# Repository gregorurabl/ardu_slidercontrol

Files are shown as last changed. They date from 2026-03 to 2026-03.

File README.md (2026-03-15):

# Slidercontrol V2.1
### Motorized Camera Slider - Sources and Hardware Documentation

**Author:** Gregor Urabl | [gregorurabl.at](https://gregorurabl.at)  
**Version:** 2.1  
**Platform:** Arduino Mega 2560 (AZ-Delivery Clone)  
**Slider:** Rollei / iFootage Shark S1

**Photos:** https://github.com/gregorurabl/ardu_slidercontrol/tree/main/Fotos_Videos

**Videos:** https://drive.google.com/drive/folders/1h0wJf8_ykMVB8sSwVJ3sm4PEZuROGbLa

> **Work in Progress** - This documentation is incomplete and subject to change without notice.

> **Disclaimer:** This project is shared for educational and personal reference purposes only. No support is provided. If you choose to replicate this project, you do so entirely at your own risk. The author accepts no responsibility for any damage to equipment, components, cameras, or any other property, nor for any personal injury, that may result from building or operating this or a similar system. Working with stepper motors, motor drivers and external power supplies involves voltages and currents that can cause permanent hardware damage if wired incorrectly. Always verify your wiring before applying power.

image (8)

---

## Table of Contents

1. [Sources & Libraries](#1-sources--libraries)
   - [1.1 Project Base](#11-project-base)
   - [1.2 Arduino Libraries](#12-arduino-libraries)
    - [Schematic](#schematic)
2. [Hardware](#2-hardware)
   - [2.1 Main Components](#21-main-components)
   - [2.2 Hardware History & Incidents](#22-hardware-history--incidents)
   - [2.3 Stepper Motor & Gearbox](#23-stepper-motor--gearbox)
   - [2.4 Camera Trigger Circuit](#24-camera-trigger-circuit)
   - [2.5 Optional Ultrasonic End-Stop Sensor](#25-optional-ultrasonic-end-stop-sensor)
   - [2.6 Controller Housing](#26-controller-housing)
3. [Pin Reference (Arduino Mega 2560)](#3-pin-reference-arduino-mega-2560)
   - [3.1 TFT Display](#31-tft-display)
   - [3.2 Touchscreen (Resistive)](#32-touchscreen-resistive)
   - [3.3 Stepper Motor Driver (A4988)](#33-stepper-motor-driver-a4988)
   - [3.4 Sonar / Camera Trigger (shared)](#34-sonar--camera-trigger-shared)
4. [Desktop Remote (Python)](#4-desktop-remote-python)
---

## Overview

Slidercontrol V2.1 is a fully self-contained motorized camera slider controller built around an Arduino Mega 2560. It drives a NEMA 17 stepper motor with planetary gearbox via an A4988 driver and provides a touchscreen UI on a 3.5" TFT shield. An optional ultrasonic sensor acts as an automatic end-stop, and a galvanically isolated camera trigger fires a Canon DSLR in sync with slider movement for timelapse sequences.

## Planned Features

| Feature | Status |
|---|---|
| Timelapse runtime pre-calculation | Planned - display estimated total duration before a timelapse run starts, based on distance, subdivisions, delay and motor speed |
| Desktop Remote Control | BETA ready - plattform (Windows/Linux/Mac OS) independent GUI for a serial remote control (Python)|
| App Remote Control | Planned - a bluetooth remote control via amartphone app.|

### Project History - Fork of Mega-Testberichte.de

This project started as a close implementation of the [Mega-Testberichte.de motorized slider guide](https://www.mega-testberichte.de/artikel/kameraslider-motorisieren) by Marco Kleine-Albers, which I recommend consulting alongside this documentation for build photos, a step-by-step walkthrough and additional context - it is the more visually complete reference.

Over time the project diverged significantly in both hardware and software. Key reasons for branching off:

- **MobaTools instead of AccelStepper:** The original guide uses AccelStepper, which generates blocking code during motor movement. When the ultrasonic end-stop sensor was added to the system (which predates the camera trigger), non-blocking motor control became a hard requirement - the sonar loop must keep running while the motor moves. MobaTools, developed by MicroBahner as an Arduino library for model railroaders (MOdel BAhn), provides a fully non-blocking stepper implementation and is optimized for fine-grained, precise movement control - exactly what smooth camera slider travel requires. The library origins in model rail applications mean it handles slow, precise, repeatable motion particularly well.
- **Planetary gearbox motor:** The motor choice with integrated 1:14 gearbox changes the tuning, microstepping strategy and speed range significantly compared to a standard NEMA 17.
- **Camera trigger system:** An entirely new hardware and software subsystem not present in the original guide.
- **Serial remote control:** Added for computer-controlled timelapse sequences.

The original guide remains the better starting point for someone new to the project. This documentation focuses on what has changed, the reasoning behind it, and the specifics of this particular build.

### Tested Payloads

The system has been tested with the following camera setups on a horizontal slider:

| Setup | Approx. Weight | Result |
|---|---|---|
| Canon EOS 7D + lens | ~1.5 kg | Reliable at all speed settings |
| Canon EOS 5D Mark IV + lens | ~2.5 kg | Reliable at all speed settings |
| Canon EOS C400 (fully rigged) | ~6 kg | Moved without issues |

The Canon C400 test in particular is notable - a cinema camera fully rigged approaches the practical limits of the slider platform itself.

#### Theoretical Maximum Load

The following is a rough estimate based on component datasheets. Real-world load capacity depends heavily on slider bearing condition, belt tension, incline angle and chosen speed.

**Motor output torque (at gearbox output shaft):**
```
T_out = T_motor × gear_ratio × efficiency
T_out = 0.52 Nm × 13.73 × 0.80 = ~5.7 Nm (theoretical peak)
```
The gearbox max permissible continuous torque is rated at **3 Nm**, which is the practical ceiling regardless of motor output.

**Force available at belt/drive:**  
Assuming a typical belt pulley radius of ~10–15 mm:
```
F = T / r = 3 Nm / 0.012 m = 250 N (~25 kg-equivalent)
```

**Real limiting factors (in order of likely constraint):**
1. **Slider rated payload** - the iFootage Shark S1 is rated for approximately 8 kg. This is the most restrictive limit for horizontal use.
2. **Gearbox max continuous torque** - 3 Nm (5 Nm momentary peak)
3. **Gearbox shaft max axial load** - 50 N (~5 kg linear force along the shaft axis)
4. **A4988 current limit** - set to ~1.18 A in this build (~70% of rated); higher current settings increase torque headroom but also heat

For horizontal use, the slider's own payload rating is the practical limit. The motor and gearbox have significant torque headroom for loads within that rating. Inclined or vertical use would require a separate calculation and is untested.

> These figures are theoretical estimates derived from component datasheets and standard engineering assumptions. They are not guaranteed values. Do not exceed the rated capacity of your slider platform.

### What This Project Does

The controller moves a camera along a slider rail at configurable speed, distance and direction. Three operating modes are available:

- **Normal Run** - moves the slider a set distance at a set speed, with optional return to start position
- **Manual Run** - continuous motor rotation for free-form positioning, start/stop via touchscreen
- **Timelapse** - divides the total travel into equal sub-steps, pauses at each position for a configurable delay, and optionally fires the camera shutter at every stop

All parameters (speed, distance, ramp, delay, subdivisions) are adjusted on the touchscreen. The controller can also be operated via serial commands over USB.

### What You Need

**Electronics**
| Item | Notes |
|---|---|
| Arduino Mega 2560 (or clone) | AZ-Delivery clone confirmed working |
| 3.5" parallel TFT LCD shield, 480×320 | MCUFRIEND_kbv-compatible |
| A4988 stepper driver breakout board | Check R_CS marking before use (see [3.3](#33-stepper-motor-driver-a4988)) |
| NEMA 17 stepper motor | 17HS19-1684s-PG14 with 1:14 planetary gearbox used here |
| 100 µF electrolytic capacitor | Motor supply decoupling, placed close to A4988 |
| 12V / 5A DC power supply | Motor supply |
| USB power bank or 5V supply | Arduino logic supply |
| 4N33 optocoupler + 390 Ω resistor | Camera trigger circuit (optional) |
| 2.5 mm TRS female jack | Camera trigger output (optional) |
| 2.5 mm male to Canon N3 female cable | Off-the-shelf adapter cable (optional) |
| HC-SR04 ultrasonic sensor | End-stop safety (optional, mutually exclusive with camera trigger) |

**Mechanical**
- Camera slider with accessible drive shaft (e.g. Rollei / iFootage Shark S1)
- 3D-printed motor mount adapted to your slider model (see [1.1 Sources](#11-project-base))

**Tools**
- Soldering iron
- Multimeter - required for A4988 current limit calibration

### Wiring Overview

```
USB Power Bank ──────────────────────── Arduino Mega 2560
                                               │
                         ┌─────────────────────┼──────────────────┐
                         │                     │                  │
                    TFT Shield            A4988 Driver        D47 / D49
                  (direct plug-in         VDD  ← 5V           Camera trigger
                   onto Mega headers)     GND  ← GND (logic)  or HC-SR04
                                          EN   ← D23
                                          STEP ← D25
                                          DIR  ← D27
                                               │
12V / 5A PSU ──── [100 µF] ──── VMOT          │
             └──────────────── GND (motor)    │
                                          1A / 1B / 2A / 2B
                                               │
                                         Stepper Motor
```

The TFT shield plugs directly onto the Arduino Mega headers - no separate display wiring required. Motor, A4988 and power supply are wired as a separate circuit. The camera trigger is a standalone optocoupler circuit connected to D47 and GND.

**Important:** The Arduino (logic) and the motor driver (power) use separate ground connections that share a common reference point only at the DC jack. See [Ground Separation](#33-stepper-motor-driver-a4988) for details.

### Serial / USB Remote Control

The controller can be operated remotely over USB via any serial terminal (e.g. Arduino Serial Monitor, PuTTY) at **115200 baud**.

Commands are comma-separated strings terminated with a newline (`\n`). Each field can optionally carry a label prefix using a colon (`label:value`) - the parser strips everything up to and including the last colon, so both formats are accepted.

**Command format:**

```
mode,speed,distance,ramp,time,steps
```

| Index | Field | Description |
|---|---|---|
| 0 | mode | `normal`, `timelapse`, or `rth` (case-insensitive) |
| 1 | speed | Motor speed (steps/s) |
| 2 | distance | Travel distance in steps |
| 3 | ramp | Ramp/acceleration length in steps |
| 4 | time | Timelapse delay between stops in seconds |
| 5 | steps | Number of timelapse subdivisions (minimum 2) |

**Examples:**

```
normal,600,33000,0,0,2
timelapse,400,33000,0,30,10
rth,0,0,0,0,0
```

Unused fields still need to be present as placeholders. For `rth`, all fields after index 0 are ignored. The controller responds with status messages over the same serial connection.

---

## 1. Sources & Libraries

### 1.1 Project Base

This project is based on a guide by Marco Kleine-Albers (Mega-Testberichte.de) and was adapted and extended for use with Adafruit TFT and MobaTools by Gregor Urabl (gregorurabl.at), optimized for the Rollei/iFootage Shark S1 slider and a planetary-geared stepper motor.

| Source | Details | URL |
|---|---|---|
| Original Guide | Marco Kleine-Albers, Mega-Testberichte.de - complete build guide incl. schematic, parts list and software base | [mega-testberichte.de/artikel/kameraslider-motorisieren](https://www.mega-testberichte.de/artikel/kameraslider-motorisieren) ✅ |
| Adaptation & Extension | Gregor Urabl (gregorurabl.at) - adapted for Adafruit TFT & MobaTools, optimized for planetary geared stepper, camera trigger extension | [gregorurabl.at](https://gregorurabl.at) |
| Display | Niunion 3.5" TFT LCD Shield, 480×320, 8-bit parallel, resistive touchscreen, MCUFRIEND_kbv-compatible - ASIN: B08KG51VLW | [amazon.de](https://www.amazon.de/dp/B08KG51VLW) ✅ |
| Motor Mount (3D Print) | Parametric mount for iFootage Shark S1 motorization. Author: Benjamin (Hamburg). Original page no longer available. | mein-slider.de/ifootage-shark-s1-motorhalterung ❌ offline |
| Camera Trigger Reference | Martyn Currey - "Using an Arduino and an optocoupler to activate a camera shutter" - basis for optocoupler circuit design, resistor calculation and jack pinout | [martyncurrey.com/activating-the-shutter-release](https://www.martyncurrey.com/activating-the-shutter-release/) ✅ |
| Microstepping Reference | A4988 driver pin mapping and microstepping mode table | [lastminuteengineers.com](https://lastminuteengineers.com/a4988-stepper-motor-driver-arduino-tutorial/) ✅ |
| A4988 Product & Datasheet | Pololu A4988 stepper driver carrier - official product page incl. schematic, pinout and datasheet | [pololu.com/product/1182](https://www.pololu.com/product/1182) ✅ |
| MobaTools Library | Arduino library by MicroBahner (f-pm+gh@mailbox.org). Originally developed for model railroaders (MOdel BAhn), optimized for precise, fine-grained stepper control - which maps directly to the needs of smooth camera slider movement. Used here as a non-blocking replacement for AccelStepper. | [github.com/MicroBahner/MobaTools](https://github.com/MicroBahner/MobaTools) ✅ |

### 1.2 Arduino Libraries

| Library | Purpose | Source |
|---|---|---|
| Adafruit_GFX | Core graphics library | Adafruit Industries |
| Adafruit_TFTLCD | TFT display driver | Adafruit Industries |
| TouchScreen | Resistive touchscreen input | Adafruit Industries |
| MCUFRIEND_kbv | Hardware-specific TFT driver | David Prentice (GitHub) |
| MobaTools | Stepper motor and timer control. Non-blocking implementation, originally developed for model railroaders (MOdel BAhn) by MicroBahner - optimized for fine-grained, precise movement. Replaces AccelStepper to enable concurrent sonar and motor operation. | [github.com/MicroBahner/MobaTools](https://github.com/MicroBahner/MobaTools) |
| NewPing | HC-SR04 ultrasonic sensor | Tim Eckel (Arduino Library Manager) |

---

## Schematic

SliderControl_Schematic

The KiCad schematic file is at `KiCad/Slidercontrol_V2_1_Corrected.kicad_sch`.

The schematic covers:
- Arduino Mega 2560 with all used pin connections
- A4988 driver with motor power supply, 100 µF decoupling capacitor and stepper motor
- Camera trigger circuit (4N33, R1, 2.5 mm jack)
- HC-SR04 ultrasonic sensor (optional, shared pins D47/D49)
- TFT shield pin mapping

Also refer to the pin reference tables in [Section 3](#3-pin-reference-arduino-mega-2560) and the circuit diagrams in [Section 2.4](#24-camera-trigger-circuit) and [Section 3.3](#33-stepper-motor-driver-a4988).

---

## 2. Hardware

### 2.1 Main Components

| Component | Description / Specification |
|---|---|
| Microcontroller | AZ-Delivery Arduino Mega 2560 Clone (replacement after hardware incident, see [2.2](#22-hardware-history--incidents)) |
| Display | 3.5" Parallel TFT Shield, MCUFRIEND_kbv-compatible, 480×320 px |
| Stepper Motor | Stepperonline 17HS19-1684s-PG14 - 1.8°/step - Planetary Gearbox 1:14 |
| Motor Driver | A4988 (final version; TMC2209 tested previously, see [2.2](#22-hardware-history--incidents)) |
| Slider Platform | Rollei / iFootage Shark S1 |
| Camera Trigger | 4N33 optocoupler + 390 Ω resistor + 2.5 mm TRS jack |
| Ultrasonic Sensor (opt.) | HC-SR04 (end-stop safety) |

---

### 2.2 Hardware History & Incidents

#### TMC2209 V2.0 - tested, not used in final version

A test with a TMC2209 V2.0 Ultra Silent 2.5A stepper driver resulted in a cable fire and the burnout of the Arduino Mega's DC-In voltage regulator. The driver was also destroyed in the process. The exact root cause could not be conclusively determined; possible contributing factors include undersized wiring, a pre-existing defect in the DC-In regulator, or an overcurrent condition caused by the driver.

Apart from slightly quieter motor operation, the TMC2209 showed no meaningful improvement in motion smoothness compared to the A4988. The stepper motor's planetary gearbox (1:14) already provides inherently smooth and consistent motion, which largely eliminates the benefit of Stealthchop. The final version therefore uses the A4988.

#### AZ-Delivery Mega 2560 Clone - replacement after hardware incident

Following the failure of the original Arduino Mega 2560, the system runs successfully on an AZ-Delivery Mega 2560 clone. Pin mapping and feature set are fully compatible with the original; all documented functions operate reliably on the clone.

---

### 2.3 Stepper Motor & Gearbox

The Stepperonline 17HS19-1684s-PG14 features an integrated planetary gearbox with a 1:14 ratio, providing high holding torque at low RPM - well suited for smooth, consistent slider travel. Microstepping is disabled in firmware because the gearbox already provides sufficient mechanical smoothing.

| Parameter | Value |
|---|---|
| Step angle | 1.8° (200 full steps/rev) |
| Gearbox ratio | 1:14 |
| Microstepping | Disabled (pins M1–M3 NC) |
| Steps/rev in firmware | 3200 (200 × 16) - constant retained for reference |

> **Note:** The 3200 steps/rev constant in the code reflects the full microstepping configuration. With the planetary gearbox and microstepping disabled, effective mechanical resolution differs. The constant is kept for potential use without the gearbox.

---

### 2.4 Camera Trigger Circuit

The camera trigger provides galvanic isolation between the Arduino and the camera using a 4N33 optocoupler. The Arduino is directly wired into the optocoupler circuit. The optocoupler output is connected via a soldered cable to a **2.5 mm TRS female jack** permanently mounted on the controller housing. From there, a commercially available **2.5 mm male to Canon N3 female adapter cable** connects to the camera.

The circuit design follows the approach described by Martyn Currey ([martyncurrey.com/activating-the-shutter-release](https://www.martyncurrey.com/activating-the-shutter-release/)), adapted for the 4N33 with a 390 Ω input resistor.

#### Signal Chain

```
Arduino D47
    │ (direct wiring)
    ▼
Optocoupler circuit (4N33 + R1 390 Ω)
    │ (soldered cable)
    ▼
2.5 mm TRS Female Jack  ←── permanently mounted on housing
    │ (commercial cable: 2.5 mm Male → Canon N3 Female)
    ▼
Camera (Canon N3)
```

#### How It Works

The Canon N3 connector places approximately 3.2V on the shutter and focus lines - **this voltage is supplied by the camera itself**, not by the Arduino. Triggering is achieved by **shorting the shutter line to ground** via the optocoupler. The optocoupler ensures there is no electrical connection between the Arduino circuit and the camera circuit, protecting the camera from any voltage on the controller side.

#### Circuit

```
Arduino D47 ──── R1 (390 Ω) ──── 4N33 Pin 1 (Anode)
                                  4N33 Pin 2 (Cathode) ──── Arduino GND
                                  4N33 Pin 5 (Collector) ── Jack Tip   ──[cable]── N3 Shutter (~3.2V)
                                  4N33 Pin 4 (Emitter) ──── Jack Sleeve ──[cable]── N3 GND
                                  4N33 Pin 3 (Base) ──── NC
                                  Jack Ring ──── NC         ──[cable]── N3 Focus (not triggered)
```

CameraTrigger

#### 2.5 mm TRS Jack Pinout

| Contact | Connected to | Via adapter cable |
|---|---|---|
| Tip | 4N33 Pin 5 (Collector) | N3 Shutter |
| Ring | NC | N3 Focus (not used) |
| Sleeve | 4N33 Pin 4 (Emitter) | N3 GND |

#### Resistor Dimensioning

| Parameter | Value |
|---|---|
| Supply voltage | 5V (Arduino digital pin) |
| LED forward voltage (4N33) | ≈ 1.2V |
| Resistor | 390 Ω |
| LED current | (5V − 1.2V) / 390 Ω ≈ **9.7 mA** |
| 4N33 maximum I_F | 60 mA |
| Arduino pin max. current | 40 mA |

#### Trigger Pulse

Arduino drives `TRIGGER_PIN` (D47) `LOW` to close the optocoupler and short the N3 shutter pin to ground, then returns `HIGH` to release. Pulse duration is configurable in firmware (default: 100 ms).

> **Note:** Only the shutter contact is triggered. Focus is not connected. For cameras requiring focus + shutter simultaneously (e.g. bulb mode), the focus line would need to be wired in parallel.

---

### 2.5 Optional Ultrasonic End-Stop Sensor

An HC-SR04 ultrasonic module can be used as an end-stop safety mechanism. It stops the motor automatically when an obstacle (e.g. the end of the slider rail) is detected within 7 cm. The module shares pins D47 and D49 with the camera trigger - **only one module can be connected at a time.**

Module detection is automatic at startup: the firmware sends a single ping at maximum range. If a response is received, Sonar Mode is activated (green indicator on display). If the ping fails, Camera Mode is activated (blue indicator).

| Parameter | Value |
|---|---|
| TRIGGER_PIN | D47 (brown wire) |
| ECHO_PIN | D49 (black wire) |
| VCC | 5V (red wire) |
| GND | GND (white wire) |
| Max. ping distance | 200 cm (configurable) |
| Stop threshold | ≤ 7 cm |
| Ping interval | 50 ms (20× per second) |

---

### 2.6 Controller Housing

The housing used in early versions of this build is the enclosure published by Marco Kleine-Albers on Thingiverse: [thingiverse.com/thing:3344179](https://www.thingiverse.com/thing:3344179). It was printed and used through several beta versions.

The original STL files are included in this repository at `3D Print/Mega-Testberichte Slider-Case (Arduino Mega+Touch LCD Sainsmart) - 3344179/` as an unmodified reference baseline.

The housing was later modified to increase internal volume for the additional camera trigger wiring and to improve structural stability through thicker walls. Modified lid files are in `3D Print/Drive_Fork/`:

| File | Description |
|---|---|
| `deckel_displayseite.v2.stl` | Modified lid - flat variant, increased wall thickness |
| `deckel_displayseite.stl` | Modified lid - raised variant, additional height for cable and electronics volume |
| `deckel_unterseite.stl` | Lid underside (modifier body) |

<details>
<summary>Show Photos</summary>

image (9)
image (10)
image (7)

Original Housing before raising lid
</details>

### 2.7 Motor Drive - Direct Drive vs. Belt Drive

**Mega-Testberichte.de approach:** The original guide attaches the motor directly to the slider's existing drive belt via a gear adapter, effectively replacing the manual knob with a motor. This removes the ability to operate the slider by hand.

**mein-slider.de housing (used as base here):** The 3D-printed motor housing from mein-slider.de was specifically designed for the iFootage Shark S1 and preserves manual operability by using a separate add-on adapter rather than replacing the original drive belt. However, it routes motor torque through a dedicated secondary drive belt, which created the sourcing problem: no correctly sized belt could be found. The only available belt was too long to tension properly.

<details>
<summary>Show Photos</summary>
   
image (1)
image (2)
image (3)
image (4)

</details>
   
**Direct drive solution:** After several experiments scaling the motor housing, a direct drive variant was developed. The motor shaft couples directly to the slider's drive element via a printed adapter, with no belt or intermediate gears.

This turned out to be the better solution in every respect:
- Full motor torque delivered directly to the slider with no belt slip or stretch
- Fewer moving parts means fewer failure points
- Smaller and simpler housing
- Manual operability of the Shark S1 is retained through the add-on adapter design

Original drive STL files from the reference design are in `3D Print/Original_Drive_STL/`.

| File | Description |
|---|---|
| `gehaeuse_unterseite_v2.stl` | Motor housing - underside |
| `gehaeuse_motorseite_v02.stl` | Motor housing - motor-facing side |
| `antrieb_v02.stl` | Drive element / motor shaft adapter |

The iterative development process - including test prints, fit experiments and the final direct drive solution - is also documented in `Fotos_Videos/`.

---

### Repository Structure

```
/
├── 3D Print/
│   ├── Drive_Fork/                          # Modified direct drive and housing files
│   │   ├── antrieb_v02.stl
│   │   ├── deckel_displayseite.stl          # Lid raised variant
│   │   ├── deckel_displayseite.v2.stl       # Lid flat variant
│   │   ├── deckel_unterseite.stl
│   │   ├── gehaeuse_motorseite_v02.stl
│   │   └── gehaeuse_unterseite_v2.stl
│   ├── Mega-Testberichte Slider-Case (Arduino Mega+Touch LCD Sainsmart) - 3344179/
│   │   └── ...                              # Original Thingiverse files (unmodified)
│   └── Original_Drive_STL/                  # Original belt drive reference files
├── Datasheets/                              # Component datasheets
├── Fotos_Videos/                            # Build photos and videos
├── KiCad/
│   └── Slidercontrol_V2_1_Corrected.kicad_sch
└── README.md
```

---

## 3. Pin Reference (Arduino Mega 2560)

### 3.1 TFT Display

The PCB silkscreen uses the prefix `LCD_` (not `TFT_`). The signal `tft_CD` in firmware corresponds to `LCD_RS` on the board - RS (Register Select) and CD (Command/Data) are the same signal: LOW = command, HIGH = data.

| Firmware Name | PCB Label | Arduino Mega Pin | Notes |
|---|---|---|---|
| tft_CS | LCD_CS | A3 | Chip Select |
| tft_CD | **LCD_RS** | A2 | Register Select (= Command/Data) |
| tft_WR | LCD_WR | A1 | Write |
| tft_RD | LCD_RD | A0 | Read |
| tft_RST | LCD_RST | A4 | Reset (can also connect to Arduino RST) |
| tft_D0 – tft_D1 | LCD_D0, LCD_D1 | 8, 9 | 8-bit data bus (low bits) |
| tft_D2 – tft_D7 | LCD_D2 – LCD_D7 | 2, 3, 4, 5, 6, 7 | 8-bit data bus (high bits) |
| *(not used)* | SD_SS, SD_DI, SD_DO, SD_SCK | 10, 11, 12, 13 | SD card interface - not used in this project |

### 3.2 Touchscreen (Resistive)

| Signal | Arduino Mega Pin | Notes |
|---|---|---|
| YP | A1 | Analog pin - shared with tft_WR |
| XM | A2 | Analog pin - shared with tft_CD |
| YM | 7 | Digital pin |
| XP | 6 | Digital pin |

> A1 and A2 are shared between the TFT data bus and the resistive touchscreen. This is handled by the MCUFRIEND_kbv and TouchScreen libraries automatically.

### 3.3 Stepper Motor Driver (A4988)

#### Control Pins (Arduino → A4988)

| Signal | Arduino Mega Pin | A4988 Pin | Notes |
|---|---|---|---|
| ENABLE | 23 | ENABLE | Active LOW - motor disabled by default |
| STEP | 25 | STEP | Step pulse |
| DIR | 27 | DIR | Direction |
| M1 | A8 | MS1 | Microstepping bit 1 - NC (disabled) |
| M2 | A9 | MS2 | Microstepping bit 2 - NC (disabled) |
| M3 | A10 | MS3 | Microstepping bit 3 - NC (disabled) |
| 5V | 5V | VDD | Logic supply |
| GND | GND | GND | Logic ground |

> RESET and SLEEP are bridged together on the A4988 breakout board (tied HIGH).

#### Ground Separation

The A4988 has two separate GND pins that must **not** be treated as a single connection:

| A4988 GND Pin | Connected to | Carries |
|---|---|---|
| GND (power side, next to VMOT) | 100 µF capacitor (−), then DC jack (−) | Motor current (up to 2A) |
| GND (logic side, next to VDD) | Arduino GND | Logic signals only (mA range) |

Both grounds share a common reference point at the power supply / DC jack, but should be routed separately on the PCB or in the schematic to avoid mixing high-current motor return paths with logic ground.

#### Motor Power (PSU → A4988)

| A4988 Pin | Connection | Notes |
|---|---|---|
| VMOT | 12V PSU (+) | Motor supply voltage - 8–35V supported |
| GND (power side) | 12V PSU (−) | Motor ground |

**100 µF electrolytic capacitor** across VMOT and GND, placed as close to the A4988 as possible. Protects the driver from voltage spikes caused by the motor's inductance.

#### Motor Coils (A4988 → Stepper)

| A4988 Pin | Stepper Wire | Coil |
|---|---|---|
| 1A | - | Coil A, terminal 1 |
| 1B | - | Coil A, terminal 2 |
| 2A | - | Coil B, terminal 1 |
| 2B | - | Coil B, terminal 2 |

> Coil assignment and wire color depend on the specific motor. For the **17HS19-1684s-PG14** consult the datasheet. Swapping both wires of one coil reverses that coil's polarity and changes rotation direction - equivalent to toggling DIR.

#### Current Limit Calibration (VREF)

The A4988 current limit must be set **before connecting the motor**. An incorrectly set current limit risks overheating or damaging the driver and motor.

**Required tools:** multimeter, small flathead screwdriver

**Formula (per Pololu):**

```
VREF = I_max x 8 x R_CS
```

| Variable | Description |
|---|---|
| VREF | Reference voltage to set (measured at potentiometer) |
| I_max | Target current limit in amps |
| R_CS | Current sense resistor value on the board |

**Determine R_CS first** by inspecting the two small SMD resistors next to the A4988 chip:

| Marking | R_CS value |
|---|---|
| R050 | 0.05 Ohm (original Pololu board) |
| R100 | 0.10 Ohm (most Chinese clones) |
| R200 | 0.20 Ohm |

**Measurement procedure:** Connect multimeter negative lead to GND, positive lead to the potentiometer wiper (the metal adjustment screw). Adjust the potentiometer while reading the voltage.

**Example calculation for the 17HS19-1684s-PG14 (rated 1.68 A):**

A conservative target of 70% of rated current reduces heat while maintaining reliable torque:

```
I_target = 1.68 A x 0.70 = 1.18 A
VREF (R100) = 1.18 x 8 x 0.10 = 0.94 V
VREF (R050) = 1.18 x 8 x 0.05 = 0.47 V
```

Per Mega-Testberichte.de, a VREF of **~0.8 V** on an R100 board was found to work well in practice with this motor type, providing reliable torque with acceptable heat generation.

> **Warning (per Pololu):** Never connect or disconnect the stepper motor while the driver is powered. This can permanently destroy the A4988. Set VREF before attaching the motor, and increase gradually from a low starting value.

### 3.4 Sonar / Camera Trigger (shared)

| Signal | Arduino Mega Pin | Notes |
|---|---|---|
| TRIGGER_PIN | 47 | Sonar: trigger output - Camera: shutter pulse (LOW-active) |
| ECHO_PIN | 49 | Sonar: echo input - Camera: not used |

> **D47 and D49 are shared between the sonar module and the camera trigger.** Automatic detection at startup determines which module is active. Never connect both simultaneously.

---

## 4. Desktop Remote (Python)

*Added March 2026*

A Python desktop application for controlling the slider over USB from a computer. Built with [customtkinter](https://github.com/TomSchimansky/CustomTkinter).



The remote covers all three operating modes available via the touchscreen UI and adds preset management and a calibration tool:

- **Normal Run** and **Timelapse** modes with all parameters (speed, distance, ramp, delay, subdivisions) configurable via sliders, including real-time cm readout for distance
- **Direction control** (Forward / Reverse) per mode
- **Manual Free Run** start/stop and Return to Home
- **Preset save/load** - stores complete parameter sets for both modes as JSON files
- **Calibration tool** - measures physical slider length and generates a per-speed timing table for accurate travel estimation
- Serial **log panel** with export to .txt
- Auto-reconnect after timelapse completion

For setup and usage, refer to [`Desktop_Remote_Manual.md`](Desktop_Remote_Manual.md).

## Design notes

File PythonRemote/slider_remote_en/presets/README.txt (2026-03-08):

This folder contains saved presets as .json files.
It can be safely emptied – the app will recreate it if needed.

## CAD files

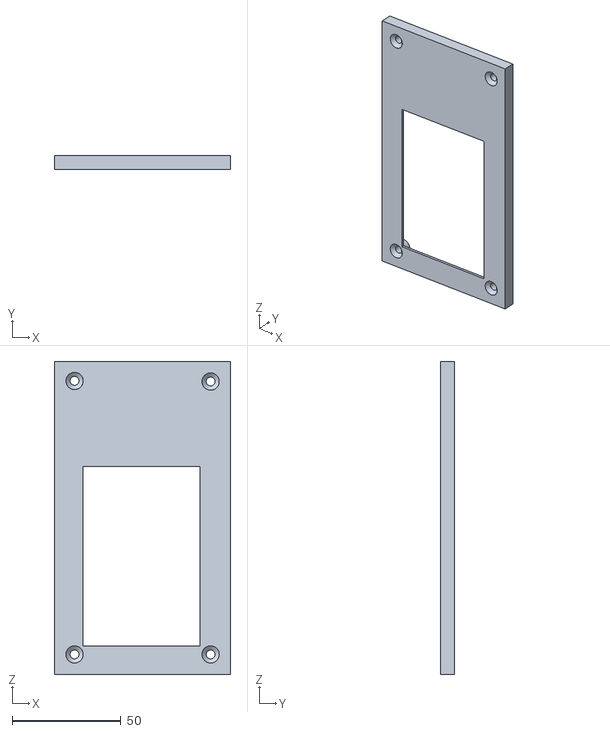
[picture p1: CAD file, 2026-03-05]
3D Print/Drive_Fork/deckel_displayseite.stl
81.0 x 6.45 x 143.9

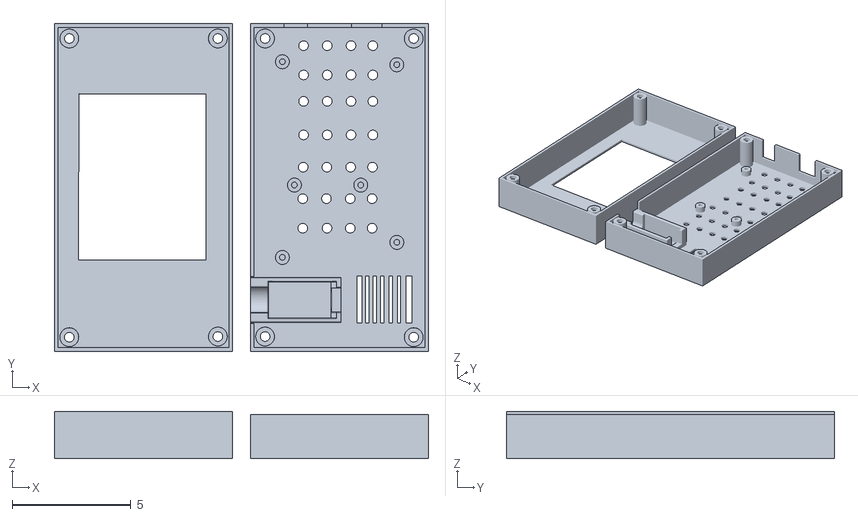
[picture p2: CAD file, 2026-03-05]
3D Print/Mega-Testberichte Slider-Case (Arduino Mega+Touch LCD Sainsmart) - 3344179/files/mka-slider-gehause1.stl
15.7 x 13.8 x 2.00

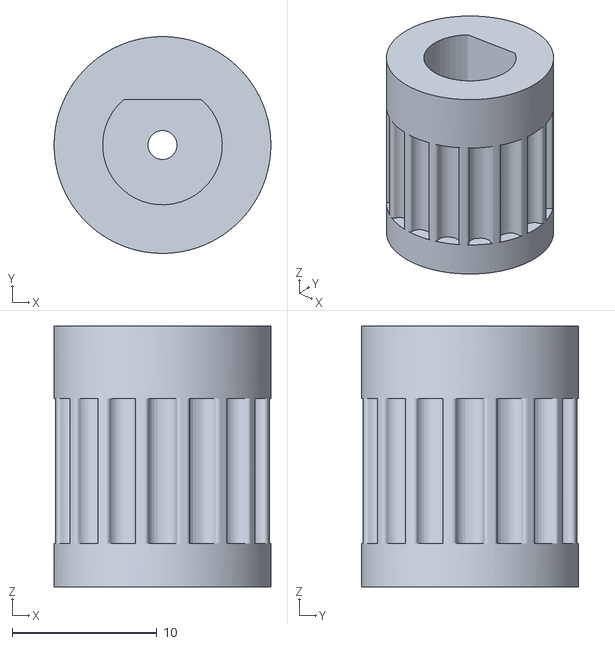
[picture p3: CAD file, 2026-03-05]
3D Print/Original_Drive_STL/Shark Antriebsrad fuer Getriebe 8mm.stl
14.9 x 14.9 x 18.0

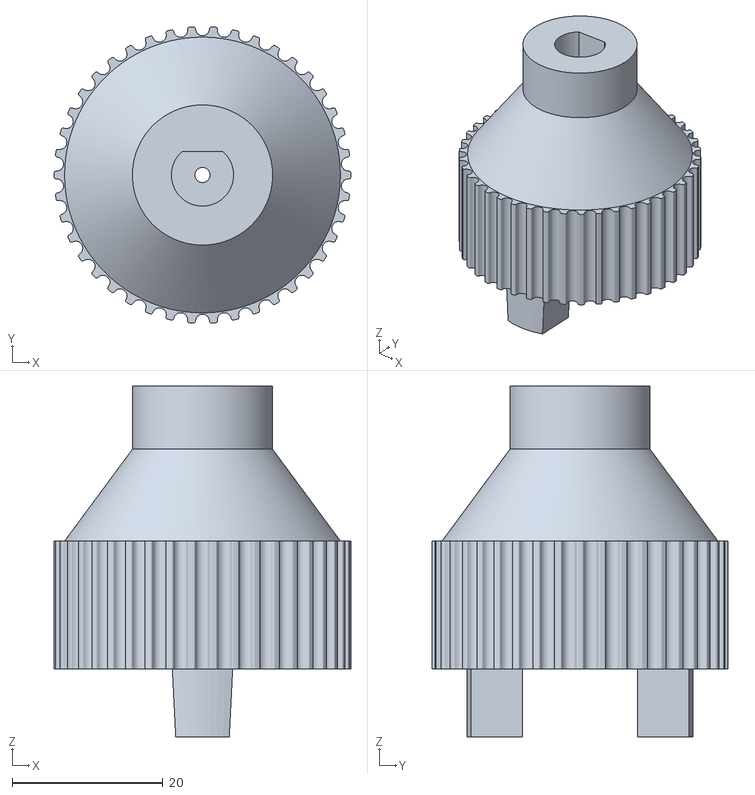
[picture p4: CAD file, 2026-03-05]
3D Print/Drive_Fork/antrieb_v02.stl
39.3 x 39.3 x 46.5

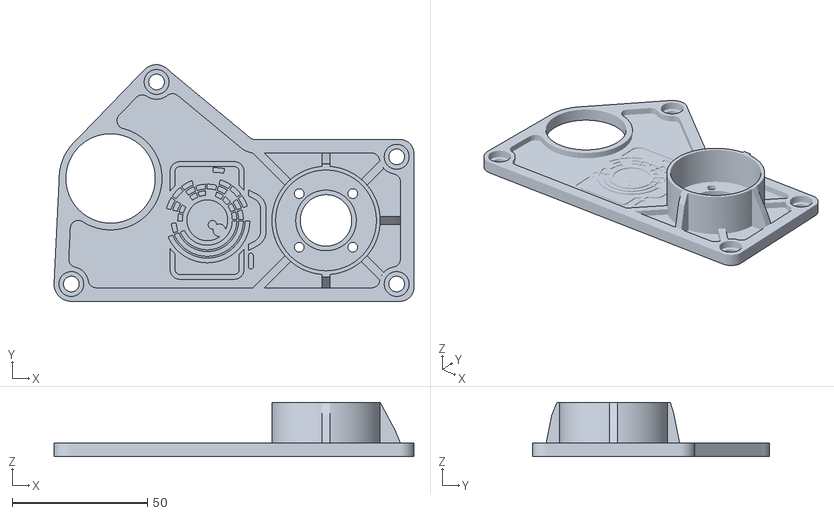
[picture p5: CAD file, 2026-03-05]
3D Print/Original_Drive_STL/Shark Nema 17 Getriebe Deckel.stl
133.0 x 87.4 x 20.0

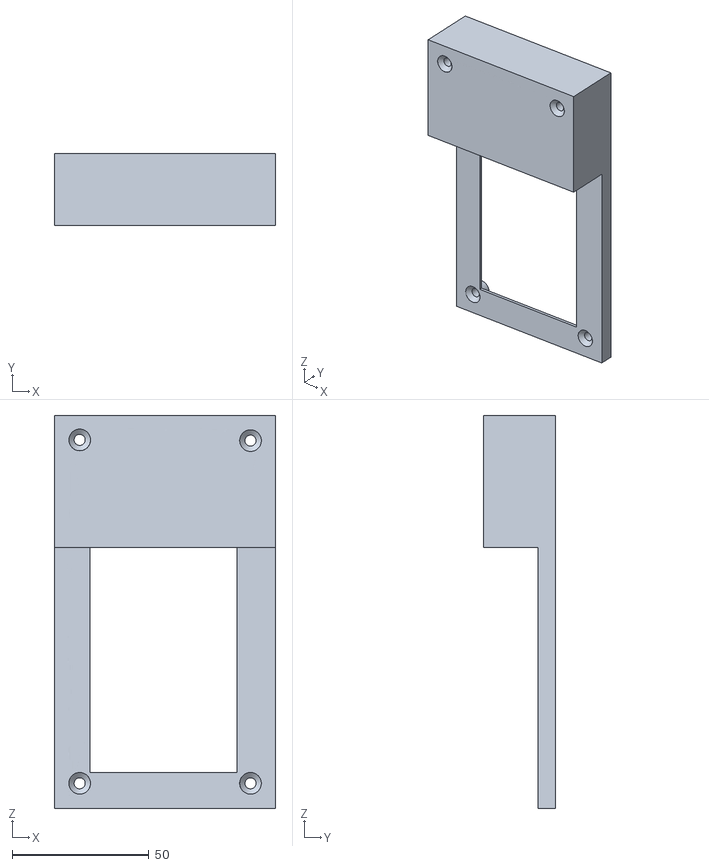
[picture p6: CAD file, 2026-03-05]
3D Print/Drive_Fork/deckel_displayseite.v2.stl
81.0 x 26.5 x 143.9

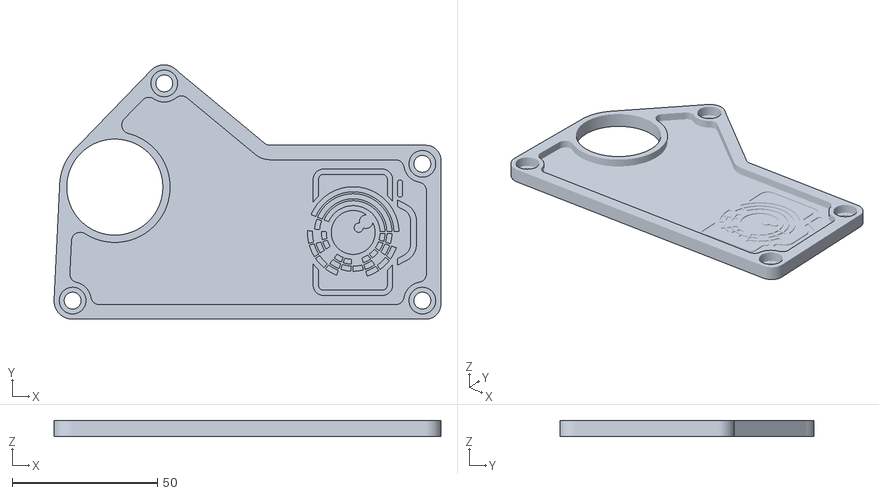
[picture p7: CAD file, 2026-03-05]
3D Print/Original_Drive_STL/Shark Nema 17 Deckel.stl
133.0 x 87.4 x 5.50

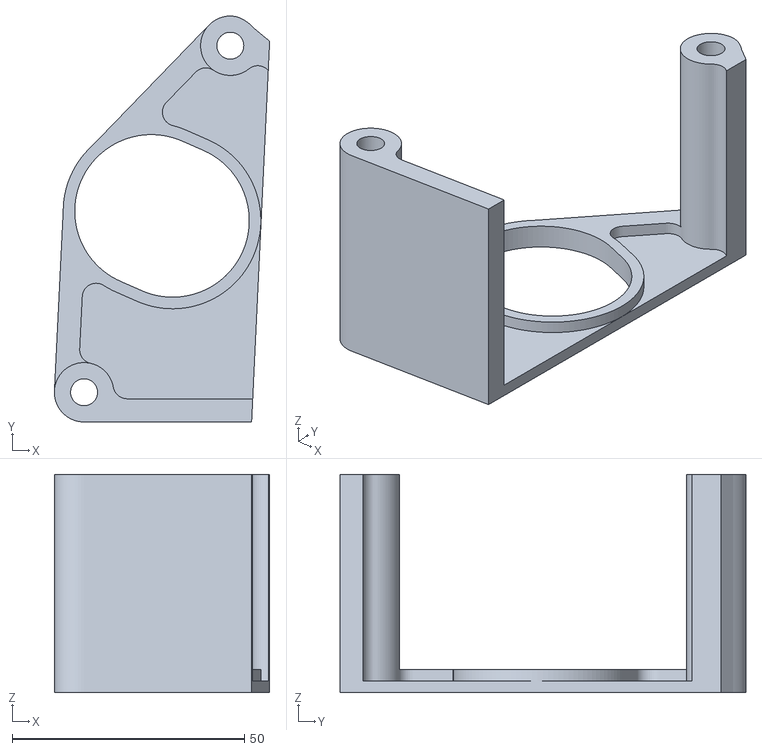
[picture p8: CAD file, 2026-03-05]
3D Print/Drive_Fork/gehaeuse_unterseite_v2.stl
46.4 x 87.4 x 47.0

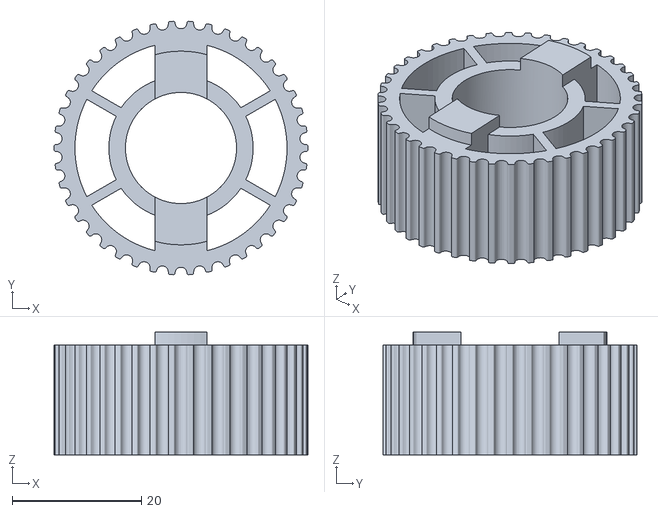
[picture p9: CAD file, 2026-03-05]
3D Print/Original_Drive_STL/Shark Antriebs Pulley.stl
39.3 x 39.3 x 19.0

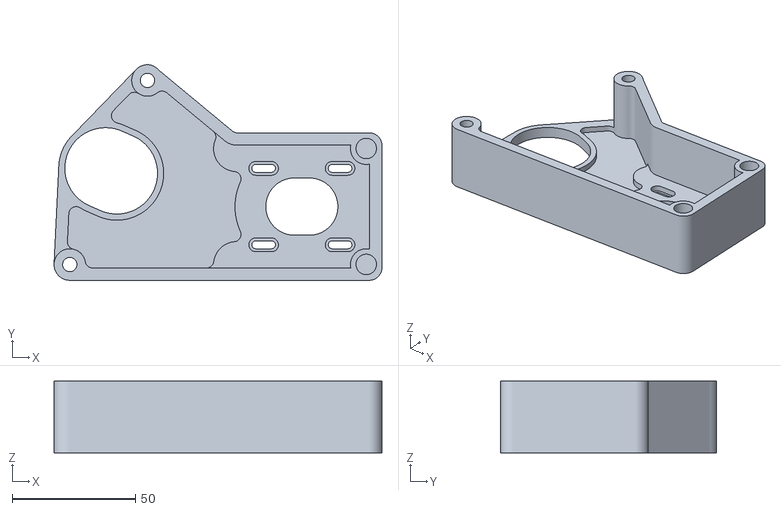
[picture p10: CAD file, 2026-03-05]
3D Print/Original_Drive_STL/Shark Nema17 Gehaeuse.stl
133.0 x 87.4 x 29.0

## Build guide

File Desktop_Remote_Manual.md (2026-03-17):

# Slider Remote Control — User Manual

**Application:** `slider_remote_en`  
**Controller firmware:** Slidercontrol V2.1.2  
**Communication:** USB Serial @ 115200 baud

---

## Table of Contents

1. [Overview](#1-overview)
2. [Installation](#2-installation)
   - [2.1 Windows](#21-windows)
   - [2.2 Linux](#22-linux)
   - [2.3 macOS](#23-macos)
3. [Build Instructions — Self-Contained Binary](#3-build-instructions--self-contained-binary)
   - [3.1 Windows](#31-windows)
   - [3.2 Linux](#32-linux)
   - [3.3 macOS](#33-macos)
4. [Application Functions](#4-application-functions)
   - [4.1 Connection Bar](#41-connection-bar)
   - [4.2 Normal Tab](#42-normal-tab)
   - [4.3 Timelapse Tab](#43-timelapse-tab)
   - [4.4 Action Buttons](#44-action-buttons)
   - [4.5 Preset System](#45-preset-system)
   - [4.6 Log Output](#46-log-output)
   - [4.7 Calibration Bar](#47-calibration-bar)
5. [Calibration System](#5-calibration-system)
   - [5.1 Overview and Purpose](#51-overview-and-purpose)
   - [5.2 Calibration Run — Section 1: Slider Length](#52-calibration-run--section-1-slider-length)
   - [5.3 Calibration Run — Section 2: Speed Calibration](#53-calibration-run--section-2-speed-calibration)
   - [5.4 Loading a Saved Calibration](#54-loading-a-saved-calibration)
   - [5.5 Speed Percentage Mapping](#55-speed-percentage-mapping)
6. [Example Commands](#6-example-commands)
   - [6.1 Normal Run](#61-normal-run)
   - [6.2 Timelapse](#62-timelapse)

---

## 1. Overview



Slider Remote Control is a desktop GUI for the Slidercontrol V2.1.2 Arduino firmware. It communicates with the controller over a standard USB serial connection and provides a graphical interface for all four operating modes:

- **Normal Run** — single-pass movement over a set distance at constant speed
- **Manual Run** — continuous free-rotation until stopped; used for positioning and calibration
- **Timelapse** — stepped sequence with configurable delay, exposure time, and subdivisions
- **Return to Home (RTH)** — returns the slider to the start position

The application is built with Python, CustomTkinter, and pyserial. It runs from source or as a self-contained single-file binary produced by PyInstaller.

---

## 2. Installation

### Prerequisites (all platforms)

- Python 3.10 or later
- pip

### 2.1 Windows

1. Download and install Python from [python.org](https://python.org). During setup, check **"Add Python to PATH"**.

2. Open Command Prompt and install the dependencies:

   ```
   pip install customtkinter pyserial
   ```

3. Navigate to the project folder and start the application:

   ```
   cd path\to\slider_remote_en
   python main.py
   ```

4. **USB driver:** If the Arduino is not listed as a COM port, install the CH340 driver (AZ-Delivery clones) or the official Arduino driver. Re-plug the USB cable after installation.

### 2.2 Linux

Install Python 3, the full standard library, and the Tkinter system package:

   ```
   sudo apt install python3-full python3-tk
   ```

Grant serial port access (required on most distributions):

   ```
   sudo usermod -aG dialout $USER
   ```

Log out and back in for the group change to take effect.

Create and activate a virtual environment, then install dependencies:

   ```
   cd path/to/slider_remote_en
   python3 -m venv venv
   source venv/bin/activate
   pip install -r requirements.txt
   ```

Start the application (venv must be active):

   ```
   python3 main.py
   ```

To activate the venv in a future session: source venv/bin/activate

The port appears as /dev/ttyUSB0 or /dev/ttyACM0. Verify with ls /dev/tty* before and after plugging the USB cable if no port is detected.

### 2.3 macOS

1. Install Python 3 via [python.org](https://python.org) or Homebrew:

   ```
   brew install python
   ```

2. Install dependencies:

   ```
   pip3 install customtkinter pyserial
   ```

3. Start the application:

   ```
   cd path/to/slider_remote_en
   python3 main.py
   ```

4. The port appears as `/dev/cu.usbserial-*` or `/dev/cu.usbmodem*`. If macOS blocks the driver, open **System Settings → Privacy & Security** and approve the kernel extension.

---

## 3. Build Instructions — Self-Contained Binary

A single-file binary requires no Python installation on the target machine. The build script `build.py` in the project root automates this via PyInstaller.

### Prerequisites (all platforms)

```
pip install pyinstaller customtkinter pyserial
```

### 3.1 Windows

```
cd path\to\slider_remote_en
python build.py
```

The binary is created at `dist\SliderRemote.exe`. It can be copied to any Windows machine and run without a Python installation. CustomTkinter theme files are bundled automatically via the `--collect-data customtkinter` flag in `build.py`.

### 3.2 Linux

Activate the venv first, then install PyInstaller into it:

```
cd path/to/slider_remote_en
source venv/bin/activate
pip install pyinstaller
python3 build.py
```

The binary is created at `dist/SliderRemote`. Mark it executable if needed:

```
chmod +x dist/SliderRemote
./dist/SliderRemote
```

The binary is linked against the glibc version present at build time. Build on the oldest target distribution for maximum compatibility.

### 3.3 macOS

```
cd path/to/slider_remote_en
python3 build.py
```

The binary is created at `dist/SliderRemote`. The `--windowed` flag suppresses the terminal window. On Apple Silicon, build natively on an M-series Mac to produce an arm64 binary.

If macOS Gatekeeper blocks the binary on first launch, right-click → **Open**, or run:

```
xattr -d com.apple.quarantine dist/SliderRemote
```

### Manual PyInstaller invocation

```
pyinstaller --onefile --windowed --name SliderRemote --collect-data customtkinter main.py
```

---

## 4. Application Functions

### 4.1 Connection Bar



Located at the top of the window.

| Control | Function |
|---|---|
| Port dropdown | Lists all available serial ports detected at startup |
| Refresh | Re-scans serial ports without restarting the application |
| Connect / Disconnect | Opens or closes the serial connection to the selected port |
| Status indicator | Shows **Connected** (green) or **Disconnected** (red) |

The application connects at **115200 baud** with a 1-second read timeout. The connection is managed in a background thread; the UI remains responsive at all times.

**Auto-connect:** On startup, if a serial port is detected, the application begins a 5-second countdown and connects automatically. During the countdown the Connect button displays `Cancel (Xs)` in red. Clicking it cancels the auto-connect and leaves the port disconnected. Auto-connect only runs once per application launch; subsequent connections must be initiated manually.

When a connection is opened, the serial handler waits 2 seconds for the Arduino to finish its reset cycle (triggered by DTR on port open) before sending any data.

If no port is found, the dropdown shows "No port found" — verify the USB connection and, on Linux, confirm group membership (see Section 2.2).

---

### 4.2 Normal Tab



Controls for a single-pass slider movement at constant speed.

**Speed (10–100%)**  
Motor speed as a percentage of the maximum. Internally converted to steps/s (`steps = pct × 12`), giving a range of 120–1200 steps/s.

**Distance (steps)**  
Travel distance in motor steps. A cm conversion is displayed below the slider and updates in real time when a calibration is loaded (see Section 5). Without a calibration, the cm value falls back to the `STEPS_PER_MM` constant in `config.py`.

Three shortcut buttons are available below the distance slider:

- **Short** — sets the distance to 17 000 steps (half-length preset)
- **Long** — sets the distance to 34 000 steps (full-length preset)
- **Forward / Reverse** — toggles the motor direction. The button label and color reflect the current selection (green = Forward, red = Reverse). Direction is encoded as a sign on the distance value sent to the controller.

**Ramp (steps)**  
Acceleration and deceleration distance in steps. The motor ramps up over this many steps and ramps down symmetrically before stopping. The slider maximum is dynamically capped at `distance / 2`. Set to `0` to disable ramping.

A **progress bar** is shown below the tab during an active Normal run. Progress is time-based (steps / speed), as the firmware does not stream step-by-step serial feedback for Normal mode.

---

### 4.3 Timelapse Tab



Controls for a stepped timelapse sequence with optional camera shutter trigger.

**Speed (10–100%)**  
Applied to each individual inter-step movement. Conversion identical to Normal tab.

**Distance (steps)**  
Total travel distance. Shortcut buttons (Short / Long) and direction toggle (Forward / Reverse) are identical to the Normal tab.

**Delay (s)**  
Pause duration in seconds at each timelapse stop, excluding the exposure time. Range: 0–900 s.

**Exposure Time**  
Shutter speed selector using standard photography values (30 s down to 1/8000 s). Available as a slider (by index) and a linked dropdown. The exposure time is added to the delay value before the command is sent — the controller receives the combined total as its wait duration, ensuring the motor does not move during the exposure.

**Subdivisions**  
Number of stops the total distance is divided into. The slider travels `distance / subdivisions` steps per move. Minimum: 2. Range: 2–1000.

**Estimated Runtime**  
A calculated total timelapse duration, displayed below the subdivisions control and updated whenever any parameter changes. Formula:

```
total = subdivisions × (travel_time + 0.05 s overhead + exposure_s + delay_s) + 5 s end wait
```

If a calibration is loaded, `travel_time` per sub-step is interpolated from the speed calibration table. Without calibration it is estimated as `steps / speed_steps_per_s`.

The runtime field is also editable: enter a target duration in `h:mm:ss`, `m:ss`, or plain seconds and the required delay is back-calculated automatically.

> Ramp is not available for Timelapse mode. The firmware does not apply ramping to individual timelapse sub-steps.

---

### 4.4 Action Buttons



Four large buttons send immediate commands to the controller. All buttons require an active connection; a warning dialog is shown if the port is not connected. A 500 ms debounce prevents accidental rapid repeated sends.

**NORMAL START**  
Validates Normal tab parameters and sends a `normal` command. The progress bar starts immediately. Invalid parameters trigger a validation dialog before any command is sent.

**MANUAL START / STOP**  
Toggles continuous free rotation. First press sends a `start` command and changes the button label to **STOP** (red). Second press sends a `stop` command and restores the original label and color. The controller reports the exact step count traveled after stopping via serial.

**TIMELAPSE START**  
Validates Timelapse tab parameters and sends a `timelapse` command. The combined wait time (`delay + exposure_s`) is sent as the `time` field. After the sequence completes, the controller automatically performs RTH; the application waits 35 s before resetting the connection to allow the return to finish.

**RTH (Return to Home)**  
Sends an `rth` command. The controller reverses the motor and returns to the position it held when the session started — the point at which the Arduino's internal step counter was at zero (i.e. where the slider physically was when the controller was powered on or last reset). Speed is determined by the current speed setting on the controller's TFT display.

---

### 4.5 Preset System



Located in the utility row below the action buttons.

**Save Preset**  
Writes all current parameter values from both tabs to a `.json` file. Includes speed, distance, ramp, direction, delay, exposure index, and subdivision count for both Normal and Timelapse.

**Load Preset**  
Restores all tab values from a selected `.json` file. A negative `distance_steps` value encodes Reverse direction; positive encodes Forward. An error dialog identifies any missing or invalid fields.

Preset JSON structure:

```json
{
  "name": "My Preset",
  "normal_speed_pct": 50.0,
  "normal_distance_steps": 33000,
  "normal_ramp_steps": 0,
  "tl_speed_pct": 30.0,
  "tl_distance_steps": 33000,
  "tl_ramp_steps": 0,
  "tl_time_s": 30,
  "tl_subdivisions": 10,
  "tl_exposure_idx": 12
}
```

The `presets/` folder is created automatically on first save.

---

### 4.6 Log Output



A scrolling read-only text field displaying all application events.

| Control | Function |
|---|---|
| Timestamps: ON / OFF | Toggles `[HH:MM:SS]` prefixes on all log entries. State reflected in button color (green = on). |
| Export Log | Saves the current log content to a `.txt` file. |
| Clear Log | Clears all log entries immediately. |

Incoming controller messages are prefixed with `Controller:`. High-frequency step-counter progress messages are suppressed from the log and consumed internally for the progress bar only.

---

### 4.7 Calibration Bar



Located at the bottom of the window.

| Control | Function |
|---|---|
| Load Calibration | Opens a previously saved `.json` calibration file and activates it in memory |
| Calibration Run | Opens the calibration modal window (requires active connection) |
| Status label | Shows the loaded file name and slider length in steps, or "No calibration loaded" |

The calibration affects the cm distance readout, the Normal run progress bar accuracy, and the Timelapse runtime estimate. See Section 5 for the full procedure.

---

## 5. Calibration System




### 5.1 Overview and Purpose

The calibration system records two hardware-specific datasets:

- **Slider length in steps** — the exact step count for the full usable travel of the physical slider
- **Speed calibration table** — measured full-length travel durations at 10 speed levels (10%–100%)

These are used as follows:

- **Timelapse runtime estimate** — per-sub-step travel time is interpolated from the speed table
- **Normal run progress bar** — estimated from travel time, more accurate with calibration loaded
- **cm readout** — derived from `STEPS_PER_MM` in `config.py` (hardware-specific, must be set correctly)

Calibration is persisted as a `.json` file and can be re-loaded without repeating the procedure.

---

### 5.2 Calibration Run — Section 1: Slider Length

Measures the exact step count of the slider's full usable travel using a manual free run.

**Prerequisites:**

- Controller connected
- Slider carriage positioned at the **zero position** (the motor-mounted end of the rail)

**Procedure:**

1. Click **Calibration Run** in the calibration bar. The modal window opens.
2. In **Section 1 – Slider Length Calibration**, confirm the slider is at the zero position.
3. Click **Start**. A `start` command (Manual Run) is sent. The slider begins moving in the Forward direction at the current speed set on the controller's TFT display.
4. When the carriage approaches the physical end of the rail, click **Record**. A `stop` command is sent. The controller stops immediately and reports the exact step count via serial (`Manual Run stopped after X Steps.`).
5. The **Steps** field is populated automatically. The **Run Duration** field shows elapsed time.
6. If the value is not plausible (e.g. the slider was stopped early), adjust it manually in the Steps field.
7. Click **Apply Settings**. The slider length is stored and RTH is triggered automatically to return the carriage to the zero position.

After Apply, the **Confirm Zero Position** button in Section 2 becomes available.

---

### 5.3 Calibration Run — Section 2: Speed Calibration

Runs the slider at 10 preset speed levels (10%–100%) and records the full-length travel time for each. Results are used for runtime interpolation in the Timelapse tab.

**Prerequisites:**

- Section 1 completed and applied
- Slider carriage back at the zero position after RTH

**Procedure:**

1. Click **Confirm Zero Position** to confirm the carriage is at the start of the rail. This unlocks **Start Speed Calibration**.
2. Click **Start Speed Calibration**. The sequence runs fully automatically in a background thread.
3. For each of the 10 speed levels, the application sends a Normal Run command for the full slider length, waits for the `Target Reached` message, records the elapsed time, then sends RTH and waits for the return before proceeding to the next speed. A progress bar and result table update in real time.
4. Each individual run times out after 10 minutes. If a timeout occurs, the sequence is aborted, a warning dialog is shown, and the **Start Speed Calibration** button is re-enabled. Section 1 (slider length) does not need to be repeated — click **Start Speed Calibration** again to retry Section 2 from the beginning. The timeout is a deadlock safeguard: the calibration thread blocks waiting for a `Target Reached` message from the controller; without a timeout, a serial dropout or controller hang would freeze the calibration UI indefinitely. Under normal operating conditions the 10-minute limit is never reached.
5. When all 10 runs are complete, the **Save Calibration** button becomes active. The calibration is activated in memory immediately without requiring a save.
6. Click **Save Calibration** and choose a filename (e.g. `shark_s1_2025.json`).

Saved calibration file structure:

```json
{
  "slider_length_steps": 33600,
  "calibration_date": "2025-03-13",
  "speed_calibration": {
    "10": 182.4,
    "20": 94.1,
    "30": 63.5,
    "40": 48.2,
    "50": 38.9,
    "60": 32.7,
    "70": 28.1,
    "80": 24.6,
    "90": 22.3,
    "100": 21.7
  }
}
```

Values in `speed_calibration` are full-length travel times in seconds at each speed percentage.

---

### 5.4 Loading a Saved Calibration

Click **Load Calibration** and select a previously saved `.json` file. The file is validated (required keys: `slider_length_steps`, `speed_calibration`) and activated in memory. The status label updates to show the file name and slider length. The calibration is active for the current session only; it must be re-loaded after restarting the application.

---

### 5.5 Speed Percentage Mapping

The UI displays speed as 10–100%. The conversion to steps/s sent in the serial command is:

```
steps_per_second = percentage × 12
```

| Display | steps/s sent |
|---|---|
| 10% | 120 |
| 50% | 600 |
| 100% | 1200 |

The divisor `12` matches the TFT UI on the controller (`speed_set / 12 = displayed percentage`), ensuring both interfaces represent the same physical speed identically.

---

## 6. Example Commands

### 6.1 Normal Run

**Scenario:** Move the slider approximately 20 cm at 50% speed, no ramp, Forward direction.

| Parameter | Setting |
|---|---|
| Speed | 50% |
| Distance | 7874 steps |
| Ramp | 0 steps |
| Direction | Forward |

Serial command sent:

```
normal,600,7874,0,0,2
```

Field mapping: `mode=normal`, `speed=600 steps/s`, `distance=7874`, `ramp=0`, `time=0` (unused placeholder), `steps=2` (minimum placeholder).

---

### 6.2 Timelapse

**Scenario:** Full-length run (34 000 steps), 20 stops, 30 s delay, 1 s exposure, 30% speed, Forward direction.

| Parameter | Setting |
|---|---|
| Speed | 30% |
| Distance | 34 000 steps |
| Delay | 30 s |
| Exposure | 1 s |
| Subdivisions | 20 |
| Direction | Forward |

The application combines delay and exposure before sending: `total_wait = 30 + 1 = 31 s`.

Serial command sent:

```
timelapse,360,34000,0,31,20
```

Field mapping: `mode=timelapse`, `speed=360 steps/s`, `distance=34000`, `ramp=0`, `time=31 s`, `steps=20 subdivisions`.

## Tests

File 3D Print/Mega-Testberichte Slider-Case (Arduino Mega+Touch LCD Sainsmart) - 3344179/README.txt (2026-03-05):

Mega-Testberichte Slider-Case (Arduino Mega+Touch LCD Sainsmart)  by mega_testberichte on Thingiverse: https://www.thingiverse.com/thing:3344179

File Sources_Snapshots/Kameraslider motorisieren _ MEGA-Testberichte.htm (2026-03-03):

Direkt zum Inhalt

MEGA-Testberichte logo (https://mega-testberichte.de/)

MEGA-Testberichte

Volltextsuche

# Kameraslider motorisieren

metis-trck

Aktualisiert am: 06.09.2023 , von Marco Kleine-Albers (https://mega-testberichte.de/autor/marco-kleine-albers)

(https://www.youtube.com/c/MEGATestberichte) (https://www.instagram.com/mega_testberichte/)

Ich habe einen Kameraslider motorisiert. Dazu verwende ich einen Arduino und einen Stepper-Motor. Alles ist komplett frei programmierbar.

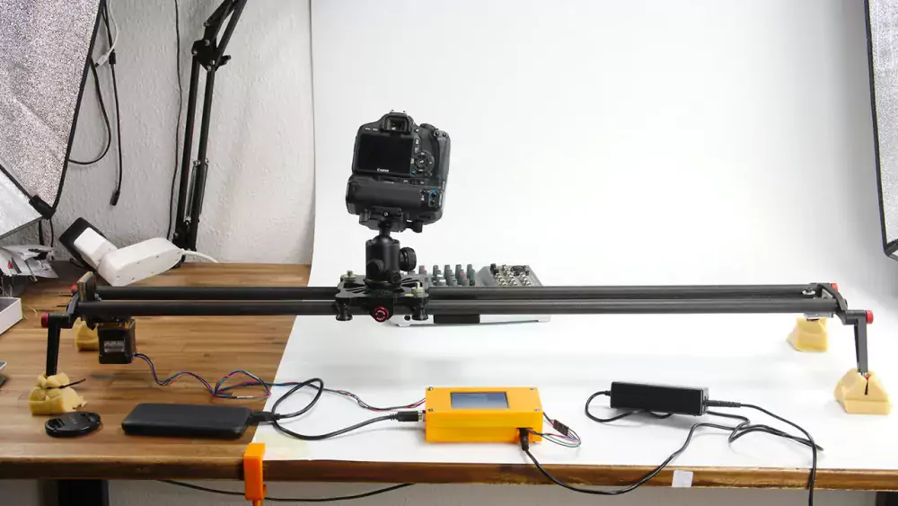
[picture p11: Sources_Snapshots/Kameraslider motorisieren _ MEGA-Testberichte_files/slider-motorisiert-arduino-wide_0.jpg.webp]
Slider motorisieren - Arduino und Stepper-Motor


Body

Hallo und herzlich willkommen zu meinem bisher umfangreichsten Do-It-Yourself Projekt. Ich hatte letztes Jahr einen Kamera-Slider von Neewer getestet (https://mega-testberichte.de/node/338) und dort erwähnt, das ich diesen motorisieren möchte. Daran habe ich die letzten Monate nebenher gearbeitet und heute zeige ich euch ausführlich, im Detail, wie ich das gemacht habe.

Info: Ich bin kein Elektriker und ich arbeite hier nur mit maximal 12V Spannung. Ihr seid selbst dafür verantwortlich was ihr macht. Ich habe bei meiner Entwicklung alles dokumentiert und bei mir funktioniert alles soweit.

Am Ende des Projekts ergibt sich dann ein motorisierter Slider mit programmierbarem Touch-Display mit dem wir automatische oder manuelle Kamerafahrten in allen möglichen Geschwindigkeiten durchführen können. Eine Zeitrafferfunktion gibt es auch. Außerdem ist es möglich eigene Programme aufzuspielen, da ich einen Arduino zur Steuerung verwenden werde.

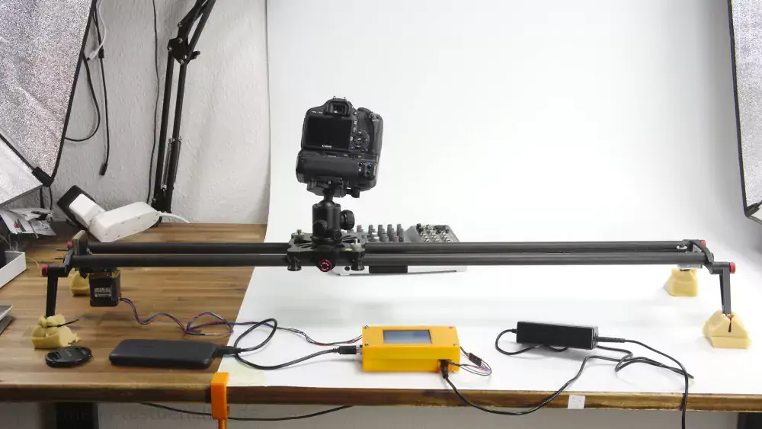
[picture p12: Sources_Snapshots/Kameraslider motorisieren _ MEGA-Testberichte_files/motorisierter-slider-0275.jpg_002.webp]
Motorisierter Kamera-Slider
 (https://mega-testberichte.de/sites/mega-testberichte.de/files/test-galeriebilder/motorisierter-slider-0275.jpg)

Motorisierter Kamera-Slider

Ich werde jetzt strukturiert auf alles eingehen. Zuerst das Material, dann der Schaltplan bzw. die Verkabelung, nötige Modifikationen am Slider und zu guter Letzt habe ich noch ein Gehäuse für die Elektronik auf meinem 3D-Drucker gedruckt, welches ich in Blender gebaut habe. Die Blender Datei habe ich auch auf Thingiverse hochgeladen (Link (https://www.thingiverse.com/thing:3344179)). Zu allererst hatte ich ein Gehäuse aus einer alten Schachtel gebaut, was aber nicht so toll aussah. Wer also keinen 3D-Drucker hat kann das auch so machen.

Info: Der 3D-Drucker ist optional. Meine erste Version kam komplett ohne in 3D gedruckte Teile aus. Sah aber nicht so schön aus.

Bild

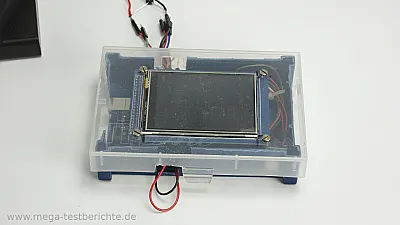
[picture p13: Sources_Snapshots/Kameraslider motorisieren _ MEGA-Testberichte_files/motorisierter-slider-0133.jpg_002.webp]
Gehäuse V1
 (https://mega-testberichte.de/sites/mega-testberichte.de/files/test-galeriebilder/motorisierter-slider-0133.jpg)

Gehäuse V1

Bild

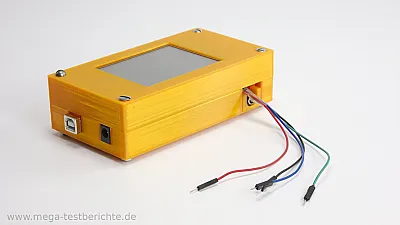
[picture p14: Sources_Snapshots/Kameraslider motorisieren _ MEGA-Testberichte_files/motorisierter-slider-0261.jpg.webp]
 (https://mega-testberichte.de/sites/mega-testberichte.de/files/test-galeriebilder/motorisierter-slider-0261.jpg)

Version 2.0

Auf die Software werde ich später noch eingehen und es wird dazu die Tage noch ein separates Video folgen, in dem ich alles genau erklären werde. Den Link zur Software ergänze ich dann im Artikel unter dem Punkt "Software".

### Video zum Artikel

Das Video ist nur ergänzend. Der Artikel enthält mehr Infos und ich werde hier eventuell auch noch Dinge korrigieren. Das geht im Video nicht.

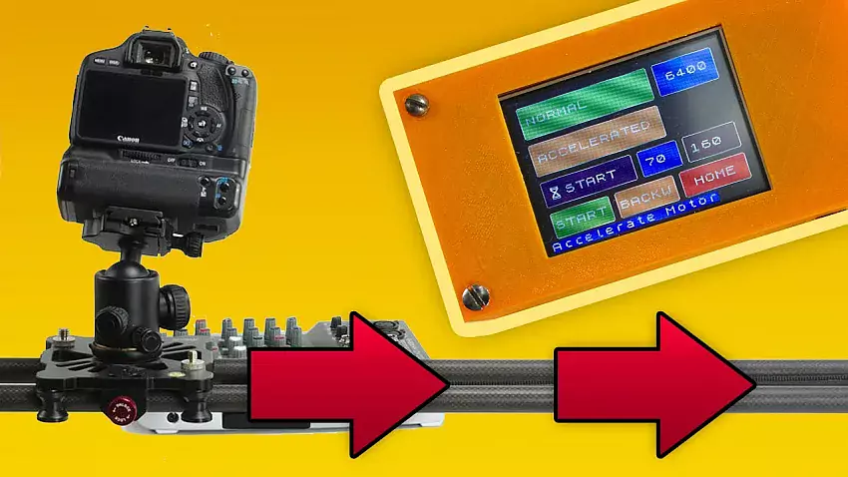
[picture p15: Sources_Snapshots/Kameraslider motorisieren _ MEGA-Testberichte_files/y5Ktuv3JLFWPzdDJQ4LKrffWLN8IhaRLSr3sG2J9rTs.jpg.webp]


Video abspielen

Wenn du dieses Video abspielst, dann akzeptierst du, dass Youtube-Cookies von Google gesetzt werden. Google-Datenschutzrichtlinie (https://policies.google.com/privacy?hl=de)

### Die Materialliste und das Werkzeug

Da dieses Projekt etwas anspruchsvoller ist, werde ich zuerst auf die Materialliste und die benötigten Werkzeuge eingehen. Neben dem Slider selbst, benötigen wir folgendes Material.

Info: Der Slider den ich motorisiert habe ist inzwischen nicht mehr erhältlich. Es gibt aber wohl einen Nachfolger. Meiner Meinung nach eignen sich Modelle mit Rohren, die nach unten offen sind.

Beispiele:

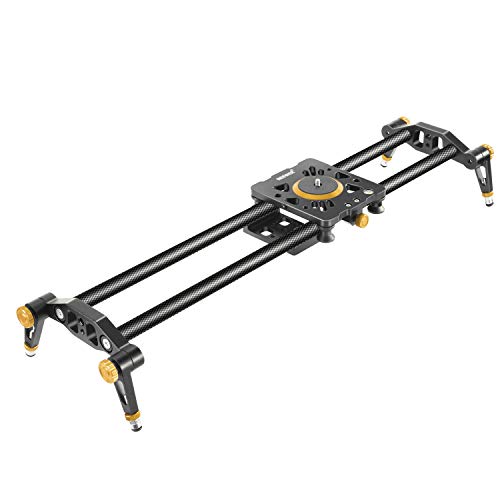
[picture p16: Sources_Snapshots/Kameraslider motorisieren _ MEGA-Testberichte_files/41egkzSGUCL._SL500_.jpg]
Neewer 100cm Kohlefaser Kameraschieber Video Stabi…
 (https://www.amazon.de/dp/B01N12JSE6?tag=megatest0c-21&amp;linkCode=ogi&amp;th=1&amp;psc=1)

Neewer 100cm Kohlefaser Kameraschieber Video Stabi…

Bei Amazon Einkaufswagen Icon (https://www.amazon.de/dp/B01N12JSE6?tag=megatest0c-21&amp;linkCode=ogi&amp;th=1&amp;psc=1)

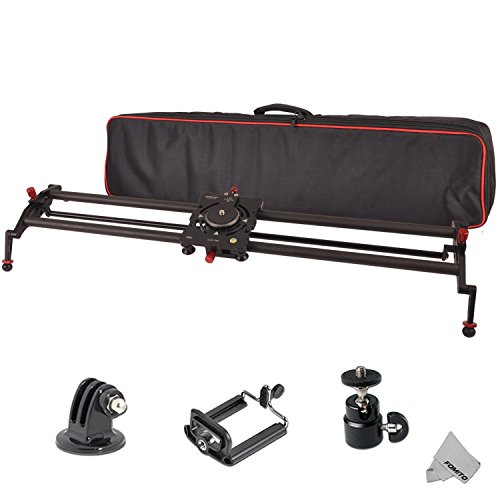
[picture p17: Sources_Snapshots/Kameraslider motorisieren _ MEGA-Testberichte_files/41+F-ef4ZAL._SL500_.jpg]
Fomito 39 Zoll 100 cm 8-Achsen-Kohlefaser Follow F…
 (https://www.amazon.de/dp/B08K3978Y4?tag=megatest0c-21&amp;linkCode=ogi&amp;th=1&amp;psc=1)

Fomito 39 Zoll 100 cm 8-Achsen-Kohlefaser Follow F…

Bei Amazon Einkaufswagen Icon (https://www.amazon.de/dp/B08K3978Y4?tag=megatest0c-21&amp;linkCode=ogi&amp;th=1&amp;psc=1)

Schrittmotor (Quimat 17HS19-2004S1)

Bild

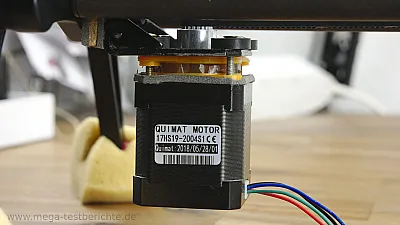
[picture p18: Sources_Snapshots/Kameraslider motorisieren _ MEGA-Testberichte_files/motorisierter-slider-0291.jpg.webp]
Schrittmotor
 (https://mega-testberichte.de/sites/mega-testberichte.de/files/test-galeriebilder/motorisierter-slider-0291.jpg)

Schrittmotor

Bild

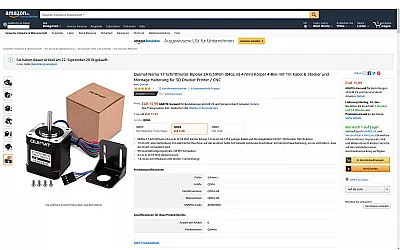
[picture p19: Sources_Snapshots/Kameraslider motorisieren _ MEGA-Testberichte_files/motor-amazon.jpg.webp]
Der Schrittmotor
 (https://mega-testberichte.de/sites/mega-testberichte.de/files/test-galeriebilder/motor-amazon.jpg)

Der Schrittmotor

Zuallererst benötigen wir einen sogenannten Schrittmotor(englisch Steppermotor) NEMA 17 Bauweise. Ich habe extra ein Modell gewählt, wo die Motorhalterung und vier Schrauben inklusive waren. Außerdem war es mir wichtig, dass das Kabel lang genug ist und an einem Ende einen Stecker hat, in den Steckbrücken passen. Das ist übrigens genau derselbe Motortyp, den wir auch bei sehr vielen 3D-Druckern finden.

Das PDF mit den technischen Details ist auf der Amazonseite in den Fragen verlinkt.

Preis ca. 15 Euro.

Schrittmotor anzeigen (https://amzn.to/2AEnW53)

Stepptermotor-Treiber A4988

Bild

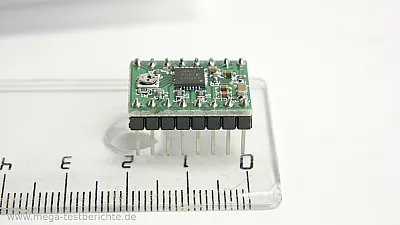
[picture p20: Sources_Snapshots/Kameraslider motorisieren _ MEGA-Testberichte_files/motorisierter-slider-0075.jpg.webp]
Schrittmotor-Treiber
 (https://mega-testberichte.de/sites/mega-testberichte.de/files/test-galeriebilder/motorisierter-slider-0075.jpg)

Schrittmotor-Treiber

Bild

Unterseite (https://mega-testberichte.de/sites/mega-testberichte.de/files/test-galeriebilder/motorisierter-slider-0079.jpg)

Unterseite

Wir benötigen außerdem einen Steppermotor-Treiber. Ich habe mich für den populären A4988(es handelt sich hier um einen Nachbau des Polulu A4988) entschieden, welchen es im 5er Pack für 10 Euro gibt. Es liegen hier auch Kühlrippen bei, welche wir auf den Chip kleben. Dieser wird nämlich warm.

Preis für 5 Stück 10 Euro.

Treiber anzeigen (https://amzn.to/2CfDtrY)

100 µF Kondensator

Bild

Kondensatoren (https://mega-testberichte.de/sites/mega-testberichte.de/files/test-galeriebilder/motorisierter-slider-0069.jpg)

Kondensatoren

Bild

Kondensator zwischen den Phasen (https://mega-testberichte.de/sites/mega-testberichte.de/files/test-galeriebilder/motorisierter-slider-arduino-4.jpg)

Kondensator zwischen den Phasen

Dann habe ich mir noch einen 100 µF Kondensator besorgt, welchen wir später zwischen die Stromkabel für den Motor löten um diesen vor Spannungsspitzen zu schützen. Die kann man auf Amazon oder Ebay kaufen, allerdings nur in Paketen.

Preis ca. 2 Euro für 10 Stück.

Kondensatoren anzeigen (https://amzn.to/2CnK0RR)

Steckbrücken

Bild

Steckbrücken (https://mega-testberichte.de/sites/mega-testberichte.de/files/test-galeriebilder/motorisierter-slider-0065.jpg)

Steckbrücken

Bild

Steckbrücken (https://mega-testberichte.de/sites/mega-testberichte.de/files/test-galeriebilder/motorisierter-slider-0059.jpg)

Steckbrücken Male/Female

Um alles zu verkabeln habe ich mir sogenannte Steckbrücken gekauft. Diese sind praktisch, weil wir sie einfach auf Pins schieben und bei Bedarf aber auch wieder entfernen können. Im Laufe meiner Entwicklung habe ich das sehr oft gemacht. Ich habe mir hier ein Paket gekauft in dem 40 Male-Male, Female-Female und Male-Female Stecker enthalten sind. Das sind alle Steckerkombinationen die es gibt.

Preis ca. 7 Euro.

Steckbrücken anzeigen (https://amzn.to/2AGMWsr)

Steckverbinder

Bild

Steckverbinder (https://mega-testberichte.de/sites/mega-testberichte.de/files/test-galeriebilder/motorisierter-slider-0053.jpg)

Steckverbinder

Bild

Eingelötet (https://mega-testberichte.de/sites/mega-testberichte.de/files/test-galeriebilder/motorisierter-slider-0025.jpg)

Eingelötet

Die Steckverbinder benötigen wir um das Shield zu erweitern bzw. um die Pins vom Arduino nach oben zu verlegen. Dazu später mehr. Außerdem habe ich einzelne Pins noch angelötet um dort dann die Steckverbinder anstecken zu können. Das ist praktischer als die Kabel fest zu verlöten (zumindest in der Entwicklung).

Preis ca. 7 Euro.

Steckverbinder anzeigen (https://amzn.to/2VQiAgi)

Arduino MEGA + Shield + Touch LCD (Sainsmart)

Bild

Arduino, Shield und Touch LCD (https://mega-testberichte.de/sites/mega-testberichte.de/files/test-galeriebilder/motorisierter-slider-0003.jpg)

Arduino, Shield und Touch LCD

Bild

Zusammengesteckt (https://mega-testberichte.de/sites/mega-testberichte.de/files/test-galeriebilder/motorisierter-slider-0035.jpg)

Zusammengesteckt

Für die Steuerung habe ich mir ein Arduino Mega gekauft bzw. ein Set von Sainsmart in dem auch noch ein TouchScreen und ein Shield enthalten sind. Das Shield wird auf den Arduino gesteckt und auf das Shield wird dann das Display gesteckt. Ein recht einfaches Konzept. Dieses Bauteil ist das teuerste, allerdings haben wir einen Touchscreen und können hier später Parameter per Touch verändern! Das ist schon eine feine Sache :)

Sainsmart Dokumentation: http://wiki.sainsmart.com/index.php/3.2"_TFT_Touch_LCD

Hier finden sich auch wichtige Details und Pinbelegungen. Außerdem wird der Kalibrierungsprozess des LCD etc. beschrieben, was wir später bei der Programmierung benötigen.

Preis 40 Euro

Arduino Set anzeigen (https://amzn.to/2Rzrek3)

Stromquellen

Bild

Powerbank oder Akkupack (https://mega-testberichte.de/sites/mega-testberichte.de/files/test-galeriebilder/motorisierter-slider-arduino-1.jpg)

Powerbank oder Akkupack

Bild

12V 5A Netzteil (https://mega-testberichte.de/sites/mega-testberichte.de/files/test-galeriebilder/motorisierter-slider-0279.jpg)

Netzteil

Wir benötigen insgesamt zwei Stromquellen. Einmal eine Stromquelle für den Arduino und eine für den Motor. Für den Arduino reicht eine simple Powerbank mit 5V oder ein Batteriepack/Batteriehalter mit 6 AA Akkus. Ich habe beides probiert und mich letztendlich für die Powerbank entschieden.

Powerbank anzeigen (https://amzn.to/2RFAm6t)

Akkupack anzeigen (https://amzn.to/2SM6mmX)

A.) Powerbank (10.000 mAh 5V) ca. 25 Euro

B.) Akkupack mit Akkus ca. 25 Euro

Info: Wenn ihr euch für den Batteriehalter entscheidet, dann achtet darauf, dass der einen DC-Stecker für den Arduino im Kabel hat. Ansonsten müsst ihr den noch kaufen und anlöten.

Für den Motor benötigen wir eine stärkere Stromquelle. Ich habe es zu Anfang mit 8x AA Akkus probiert. Das lief jedoch nicht sehr stabil bzw. war relativ schnell leer, da die Voltzahl eines Akkus schnell unter 1,2V fiel. Also habe ich mir ein 12V 5A Netzteil mit einem DC-Adapter besorgt, welches ich dann letztendlich als Stromquelle für den Motor verwendet habe.

Bild

8X Batteriehalter (https://mega-testberichte.de/sites/mega-testberichte.de/files/test-galeriebilder/motorisierter-slider-0085.jpg)

8x Batteriehalter ohne Stecker

Bild

DC-Adapter (https://mega-testberichte.de/sites/mega-testberichte.de/files/test-galeriebilder/motorisierter-slider-0179.jpg)

DC-Adapter

Bei diesem Netzteil war der Adapter inklusive. Diese Adapter kann man aber auch separat kaufen. Dann aber meist nur in Paketen von ca. 10 Stück.

Netzteil anzeigen (https://amzn.to/2RIeA1Y)

Preis 12 Euro.

Zahnriemen und Führungsräder

Bild

Zahnriemen mit Führungsrad (https://mega-testberichte.de/sites/mega-testberichte.de/files/test-galeriebilder/motorisierter-slider-0101.jpg)

Zahnriemen mit Führungsrad

Bild

Zweites Rad (https://mega-testberichte.de/sites/mega-testberichte.de/files/test-galeriebilder/motorisierter-slider-0121.jpg)

Zweites Rad

Für die Führung des Sliders benötigen wir außerdem noch einen Zahnriemen und zwei passenden Zahnriemenführungsräder. Das eine Rad kommt ans eine Ende des Sliders auf den Motor und das andere Rad an andere Ende. Über diese beiden Räder verläuft dann der Zahnriemen. Der Zahnriemen wird später noch mit einer Klemme am Slider befestigt. Diese Klemme habe ich von Thingiverse geladen, dann in Blender massiv modifiziert und ausgedruckt. Aber auch hier ist ein 3D-Drucker nicht zwingend erforderlich. Meine erste Version dieser Klemme bestand aus zwei Aluwinkeln zwischen welche der Zahnriemen geklemmt wurde. Der Zahnriemen ist bei mir ca. 190 cm lang. Zwei Meter reichen.

Bild

Version 1 (https://mega-testberichte.de/sites/mega-testberichte.de/files/test-galeriebilder/motorisierter-slider-0113.jpg)

Version 1

Bild

Version 2.0 (https://mega-testberichte.de/sites/mega-testberichte.de/files/test-galeriebilder/motorisierter-slider-0155.jpg)

Zahnriemen-Klemme(clamp)

Zahnriemen und Führungsräder anzeigen (https://amzn.to/2QCmR2W)

Preis 8 Euro

Bild

Schrauben (https://mega-testberichte.de/sites/mega-testberichte.de/files/test-galeriebilder/motorisierter-slider-0297.jpg)

Schrauben

Bild

Schrauben für das Gehäuse (https://mega-testberichte.de/sites/mega-testberichte.de/files/test-galeriebilder/motorisierter-slider-0243.jpg)

Schrauben für das Gehäuse

Wir benötigen außerdem noch ein paar Schrauben für die Befestigung am Slider und für das Gehäuse selbst.

- Vier Schrauben für das Gehäuse.
- Schraube als Führung für das Zahnriemenrad. Befestigungsschraube für den Aluwinkel.
- Drei Schrauben für die Befestigung der Motorhalterung.
- Sechs Schrauben für das Arduino-Board bzw. der Montage im Gehäuse.

Bild

Arduino Mega (https://mega-testberichte.de/sites/mega-testberichte.de/files/test-galeriebilder/motorisierter-slider-0217.jpg)

Arduino Mega

Bild

Zahnriemen mit Rad (https://mega-testberichte.de/sites/mega-testberichte.de/files/test-galeriebilder/motorisierter-slider-0119.jpg)

Zahnriemen mit Rad

Den Motor habe ich mit drei Gewindeschrauben befestigt. Welche Dicke diese haben hängt davon ab, wie groß die Befestigungslöcher sind die ihr bohrt. Ich habe 2,5mm dicke und 3,5 cm lange Schrauben genutzt. Passende Muttern benötigen wir natürlich auch noch. Das ist jedoch vom verwendeten Slider und den Gummischeiben abhängig! Für das Gehäuse habe ich vier, 4,2 cm lange und 4 mm dicke Schrauben, samt Muttern, verwendet. Die gab es so nicht direkt zu kaufen und ich habe sie abgesägt.

Für das zweite Zahnriemenführungsrad habe ich in einen bereits vorhandene Aluwinkel ein Loch gebohrt und das Rad dann mit einer Schraube und Muttern befestigt. Da hatte ich den 3D-Drucker noch nicht, sonst hätte ich dieses Teil wohl eher ausgedruckt. Die Schraube für die Befestigung passte bei mir in das bereits vorhandene Loch im Slider, ein standard 3/8 Zoll Stativgewinde. Wenn das alles befestigt ist kann der Schlitten mit der Hand verschoben werden.

Am Motor selbst habt ihr noch zwei Dämpfer gesehen, welche ich gebastelt habe um Vibrationen zu minimieren. Diese waren Anfangs mehr als übel, was aber vorallem daran lag, dass ich den Motor im Fullstepmodus betrieben habe. Mit Microstepping, 1/16 waren die Vibrationen dann weg. Das wusste ich Anfangs aber nicht und dazu werde ich euch im Video zum Code(Programm) mehr erzählen.

Diese Dämpfer müssen also nicht unbedingt sein, außer ihr habt Probleme mit Vibrationen. Den viereckigen Dämpfer habe ich aus Moosgummi und Kork gebaut. Der Motordämpfer ist ein Modell von Thingiverse und dazwischen habe ich einen Gummiring gelegt. Solche Dämpfer kann man aber auch kaufen (https://amzn.to/2D2jD5m), ein 3D-Drucker ist also nicht zwingend erforderlich.

Mein 3D-Gehäuse bei Thingiverse: https://www.thingiverse.com/thing:3344179

Motordämpfer: https://www.thingiverse.com/thing:1826103

Die Klemme für den Zahnriemen müsst ihr eventuell selber bauen, da es davon abhängt wie euer Slider gebaut ist und wie ihr Löcher bohrt. Ich habe meine Klemme so designt, dass diese auf die zwei bereits vorhandenen Löcher,auf der Unterseite des Schlittens, passt.

Mein Remix der Belt-Clamp auf Thingiverse: https://www.thingiverse.com/thing:3346755

Werkzeuge habe ich folgende verwendet:

1. Schraubenzieher
2. Metallsäge
3. Bohrer
4. Akkuschrauber
5. Standbohrmaschine
6. Metallfeilen
7. Lötkolben (grob)
8. 3D-Drucker (für Gehäuse, Zahnriemen-Klemme und Dämpfer)
9. Multimeter

Finale Kalkulation

Preise zum Zeitpunkt 10.01.2018

| Preis | Link
Slider | 60 €
Stepper-Motor | 15 €
A4988 Treiber | 10 €
Steckpins | 7 €
Kondensatoren | 2 €
Steckbrücken | 7 €
Arduino+LCD+Shield | 40 €
Powerbank | 25 €
12 V 5A Netzteil | 12 €
Zahnriemen und Führungsräder | 8 €
Summe | 186 €

Bedenkt aber, dass wir noch einige Teile über haben. Pins, Steckbrücken und Steppertreiber!

### Der Schaltplan und Verkabelung

Schaltplan/Verkabelung (https://mega-testberichte.de/sites/mega-testberichte.de/files/test-galeriebilder/arduino_schema.jpg)

Schaltplan/Verkabelung

Jetzt wo wir alle Teile beisammen haben werde ich euch den Aufbauplan zeigen. Jetzt kommen wir erstmal zur Theorie bzw. zur Verkabelung.

Zuerst verbinden wir den A4988 mit dem Arduino.

- Wir verbinden "Direction" mit Pin 8 des Boards und STEP mit Pin 10.
- SLEEP und RESET überbrücken wir mit einem Kabel.
- MS3, MS2 und MS1 sind drei Pins, welche später für die Steuerung des Microsteppings benötigen und wir verbinden diese hier mit A0, A1 und A2.

Als nächstes müssen wir die Kabel für die Logikspannung verbinden.

- Der GND Pin des A4988 wird mit dem GND Pin des Arduino verbunden und der VDD PIN mit dem 5V Pin am Arduino.

Datenblatt - Spulen (https://mega-testberichte.de/sites/mega-testberichte.de/files/test-galeriebilder/datenblatt.png)

Datenblatt - Spulen

Als nächstes haben wir vier Pins für den Motor. B1, A1 und 2A und 2B. Hier ist es wichtig, dass die Kabel vom Motor korrekt verbunden werden und welche Farben zu welcher Spule führen finden wir im Datenblatt. Ihr seht hier das Datenblatt und hier ist gekennzeichnet das black und green zu einer Spule gehören und red und blue zur anderen.

- Wir verbinden jetzt also schwarz(black) mit 1B und grün(green) mit 1A, sowie rot(red) mit 2A und blau(blue) mit 2B.

Wenn ihr diese Motor-Kabel falsch anschließt, dann zuckt der Motor später nur und dreht sich nicht richtig!

Der Motor selbst benötigt allerdings auch noch eine eigene Stromquelle.

- Diese wird mit GND und VMOT verbunden.

Diese Kabel Führen zum Netzteil. Zwischen beide Phasen habe ich dann noch einen 100 µF Kondensator gelötet um den Motor vor Spannungsspitzen zu schützen. Zu guter Letzt benötigt der Arduino selbst noch Strom. Es gibt dabei einen USB und einen DC-Anschluss. Ich habe meine 5V 10.000 mAh Powerbank an den USB-Anschluss angeschlossen.

Info: Bei den Stromkabeln(Farbe) ist bei mir schwarz=Minus und rot=Plus.

Die Pinbelegungen(Logikpins) der Kabel sollten wir uns notieren, denn diese benötigen wir nachher im Programm. Je nachdem wie ihr alles verkabelt müsst ihr diese Werte nämlich im Programm anpassen!

### Löten

Bild

Eingelötete Pins (https://mega-testberichte.de/sites/mega-testberichte.de/files/test-galeriebilder/motorisierter-slider-0025.jpg)

Eingelötete Pins

Bild

Shield blockiert Pins des Arduino (https://mega-testberichte.de/sites/mega-testberichte.de/files/test-galeriebilder/motorisierter-slider-0031.jpg)

Shield blockiert Pins des Arduino

Das Shield und der Touchscreen sind schnell aufgesteckt und im ersten Moment ist das sehr praktisch. Wie man jetzt aber sehen kann, sind die ganzen Pins bzw. Anschlüsse durch die Platine blockiert. Aus diesem Grund habe ich mir auch diese Pinleisten besorgt. Das Shield hat nämlich freie löcher in die wir die Pinleisten einlöten können um dann von oben die Anschlüsse des Arduinos erreichen zu können. Hier im Bild seht ihr eine eingelötete Pinleiste und ich habe dann seitlich auch noch Pins angelötet, damit ich die Kabel dort einstecken kann.

Bild

Nach Innen gerichtet (https://mega-testberichte.de/sites/mega-testberichte.de/files/test-galeriebilder/motorisierter-slider-0207.jpg)

Besser: Nach Innen gerichtet

Bild

So besser nicht (https://mega-testberichte.de/sites/mega-testberichte.de/files/test-galeriebilder/motorisierter-slider-0177.jpg)

So besser nicht!

Ich empfehle euch allerdings die Pins nicht nach außen einzulöten, sondern nach innen. Das sieht dann so aus und das ist besser, da so später alles besser ins Gehäuse passt bzw. das Gehäuse nicht unnötig breiter gemacht werden muss.

Info: Meine Lötstellen sind nicht die schönsten, halten aber. Ich sollte mir mal einen Feinlötkolben zulegen.
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

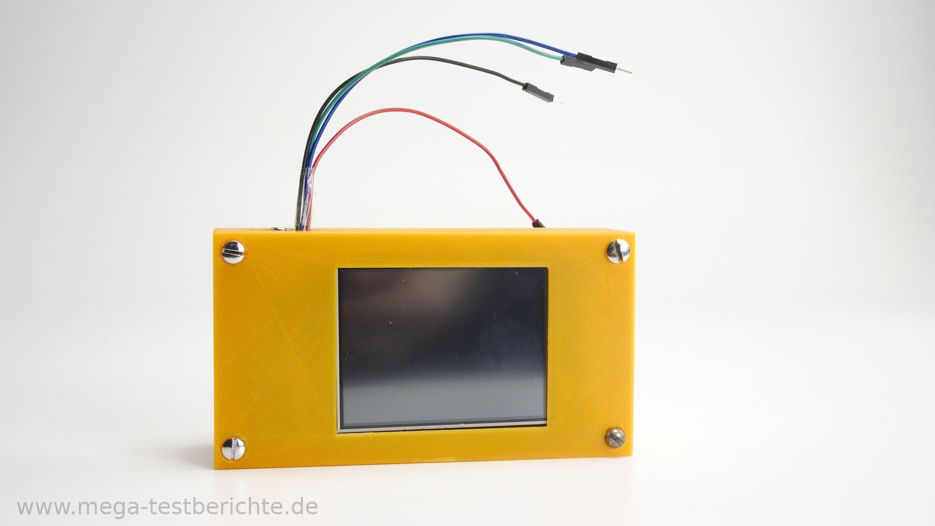
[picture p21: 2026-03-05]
3D Print/Mega-Testberichte Slider-Case (Arduino Mega+Touch LCD Sainsmart) - 3344179/images/motorisierter-slider-0267.jpg

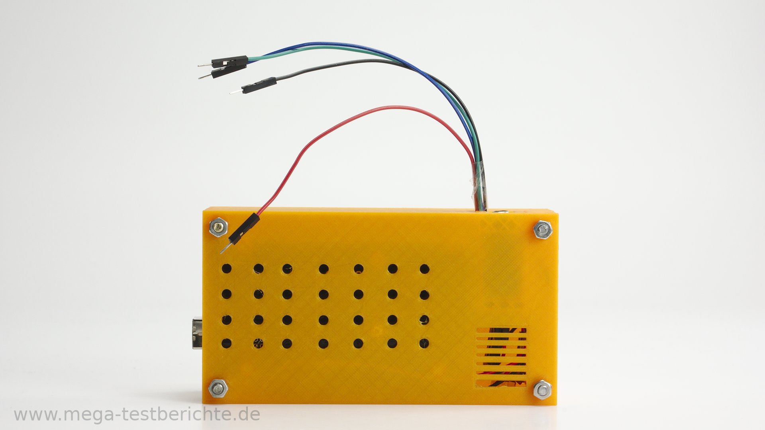
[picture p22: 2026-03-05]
3D Print/Mega-Testberichte Slider-Case (Arduino Mega+Touch LCD Sainsmart) - 3344179/images/motorisierter-slider-0271.jpg

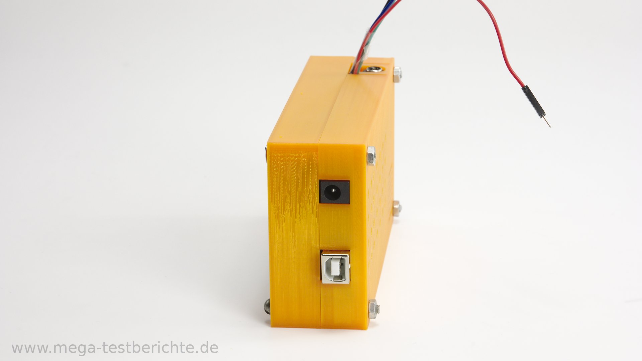
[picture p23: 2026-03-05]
3D Print/Mega-Testberichte Slider-Case (Arduino Mega+Touch LCD Sainsmart) - 3344179/images/motorisierter-slider-0265.jpg

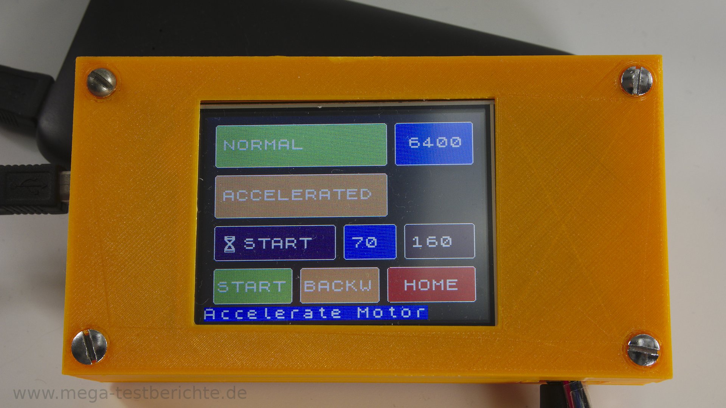
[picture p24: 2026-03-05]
3D Print/Mega-Testberichte Slider-Case (Arduino Mega+Touch LCD Sainsmart) - 3344179/images/motorisierter-slider-arduino-8.jpg

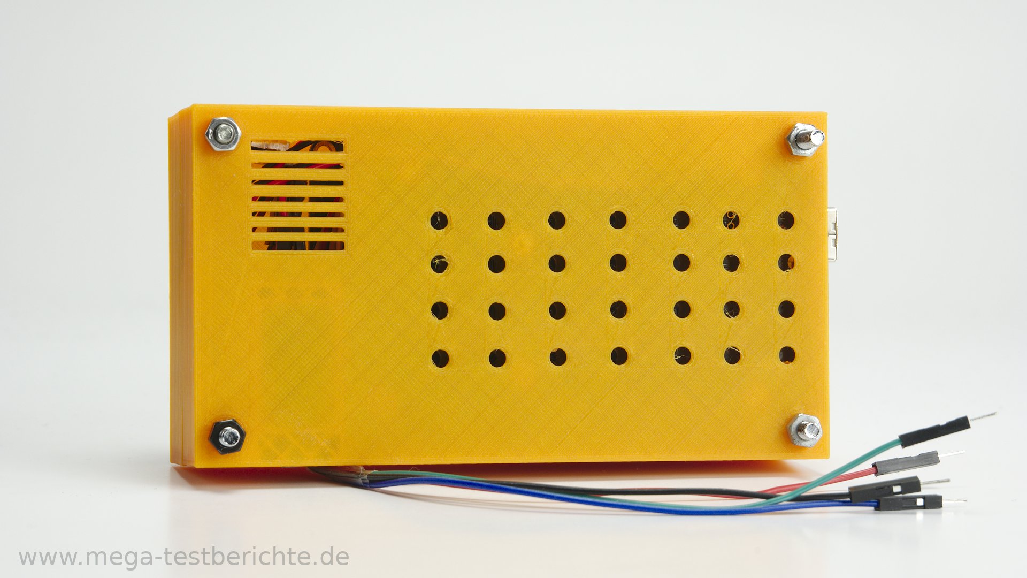
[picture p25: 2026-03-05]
3D Print/Mega-Testberichte Slider-Case (Arduino Mega+Touch LCD Sainsmart) - 3344179/images/motorisierter-slider-0253.jpg

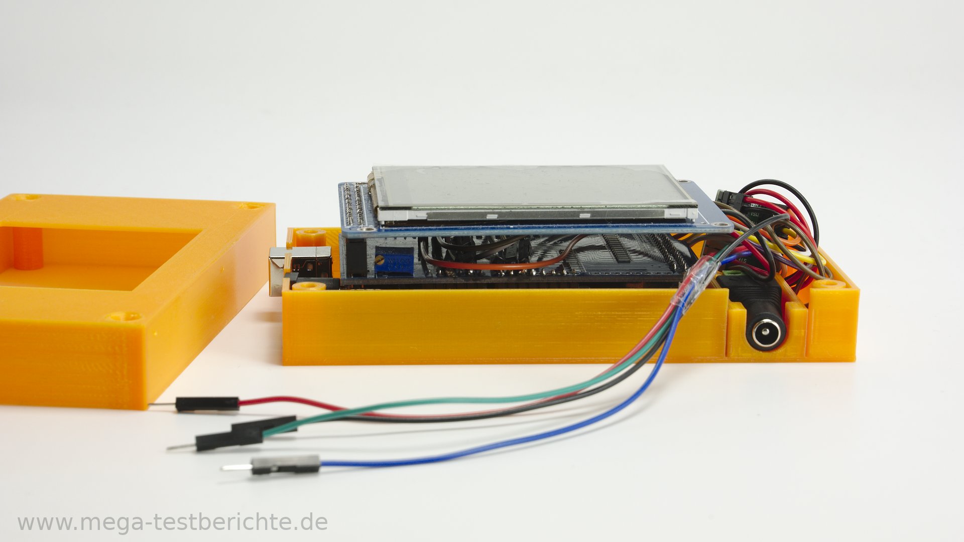
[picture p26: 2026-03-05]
3D Print/Mega-Testberichte Slider-Case (Arduino Mega+Touch LCD Sainsmart) - 3344179/images/motorisierter-slider-0227.jpg

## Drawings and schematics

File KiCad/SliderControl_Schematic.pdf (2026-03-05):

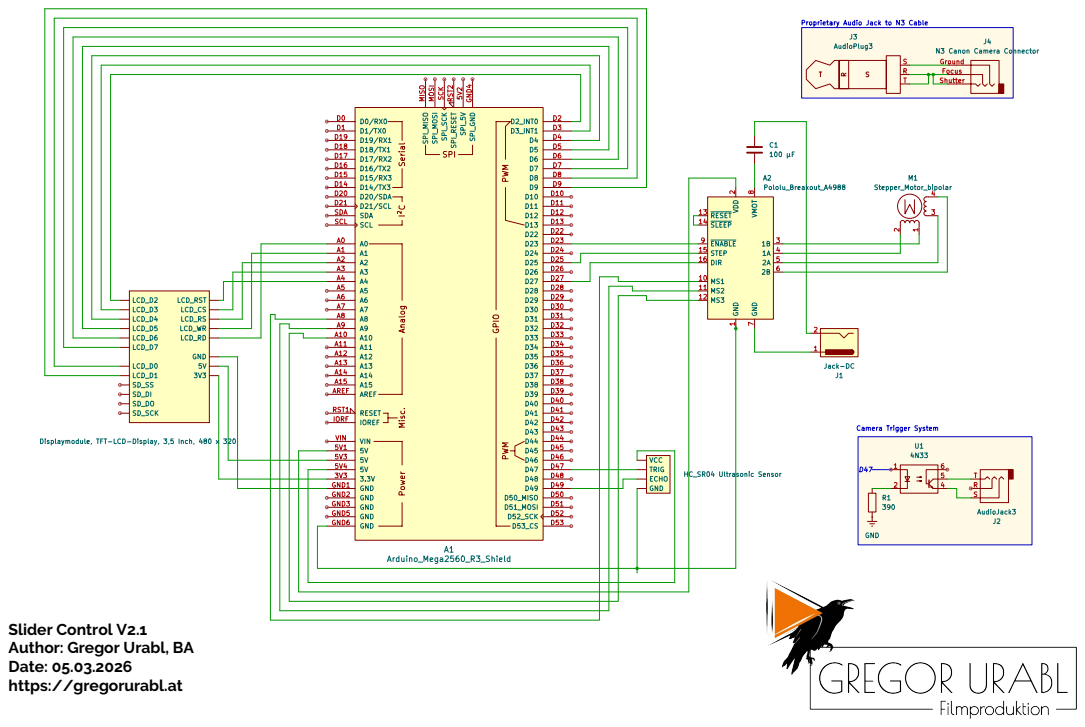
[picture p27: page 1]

Slider Control V2.1
Author: Gregor Urabl, BA
Date: 05.03.2026
https://gregorurabl.at

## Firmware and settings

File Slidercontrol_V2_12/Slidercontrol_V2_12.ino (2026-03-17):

/* Slider Control V2.1 for 3.5" Parallel TFT-tft Shield Display with Adafruit_GFX
// Loosely based on a Project by Mega-Testberichte.de - Marco Kleine-Albers
// Variant for Adafruit TFT & Moba Tools by Gregorurabl.at - Gregor Urabl
// Optimized for Rollei/iFootage Shark S1 Slider & Stepperonline 17HS19-1684s-PG14 Planetary Geared Stepper Motor

//1,8°, 360/1,8 = 200
//200 steps is a full turn in fullstep mode
//use microstepping for smoother motion. see later in code

Standard TFT tft Pin Mappings:

*pin usage as follow:
*                  tft_CS  tft_CD  tft_WR  tft_RD  tft_RST  SD_SS  SD_DI  SD_DO  SD_SCK 
*     Arduino Uno    A3      A2      A1      A0      A4      10     11     12      13   
                         
*Arduino Mega2560    A3      A2      A1      A0      A4      10     11     12      13                           

*                  tft_D0  tft_D1  tft_D2  tft_D3  tft_D4  tft_D5  tft_D6  tft_D7  
*     Arduino Uno    8       9       2       3       4       5       6       7
*Arduino Mega2560    8       9       2       3       4       5       6       7 

*Remember to set the pins to suit your display module!
*/

#include <Adafruit_GFX.h> // Core graphics library
#include <Adafruit_TFTLCD.h> // tft Library
#include <TouchScreen.h> // Touchscreen Library
#include <MCUFRIEND_kbv.h> // Touchscreen Hardware-specific library
#include <MobaTools.h> // Motor Control Library

// Colors
#define BLACK       0x0000
#define WHITE       0xFFFF
#define RED         0xF800
#define GREEN       0x07E0
#define BLUE        0x001F
#define ORANGE      0xFD20      
#define DARKCYAN    0x03EF      
#define DARKGREY    0x7BEF   
#define LIGHTGREY   0xC618     

//debug/msg
int x, y;
String msg="";
char text_buffer[80];

//////////////////////////////////
// Serial Communication Setup
//////////////////////////////////
const unsigned int MAX_MESSAGE_LENGTH = 100;
char *token;
const char *delimiter_comma =",";
const char *delimiter_dots =":";

String serialControlMessage[6];
String serialControlValues[6];

//////////////////////////////////
// Optional Sonar Module Setup - Module works as emergency break in Normal & Manual Mode and stops the motor before the slider crashes. Requires attached Sensor Module and Obstacle at End of Slider.
//////////////////////////////////
#include <NewPing.h>

#define TRIGGER_PIN   47 // Arduino pin tied to trigger pin on ping sensor. BROWN / Also used for Camera Trigger
#define ECHO_PIN      49 // Arduino pin tied to echo pin on ping sensor. BLACK
#define MAX_DISTANCE 200 // Maximum distance we want to ping for (in centimeters). Maximum sensor distance is rated at 400-500cm.

/*
White -> gnd
49 Black -> Echo
47 Brown -> Trig
Red -> vcc

OR for Camera Module:
47 Brown/Trigger -> Camera Trigger
GND -> Camera GND
*/

NewPing sonar(TRIGGER_PIN, ECHO_PIN, MAX_DISTANCE); // NewPing setup of pins and maximum distance.

unsigned int pingSpeed = 50; // How frequently are we going to send out a ping (in milliseconds). 50ms would be 20 times a second.
unsigned long pingTimer;     // Holds the next ping time.
boolean sonar_attached = false;

//////////////////////////////////
// Camera Module Setup
//////////////////////////////////
boolean camera_attached = false;
unsigned long camera_trigger_duration = 100; // Camera trigger pulse duration in ms (adjustable based on camera requirements)
int photo_counter = 0; // Counter for triggered photos

//////////////////////////////////
// Screen Setup
//////////////////////////////////

#define tft_CS A3 // Chip Select goes to Analog 3
#define tft_CD A2 // Command/Data goes to Analog 2
#define tft_WR A1 // tft Write goes to Analog 1
#define tft_RD A0 // tft Read gies to Analog 0

#define tft_RESET A4 // Can alternately just connect to Arduino's reset pin

// define pins for resistive touchscreen
#define YP A1 // must be an analog pin, use "an" notation!
#define XM A2 // must be an analog pin, use "an" notation!
#define YM 7 // can be a digital pin
#define XP 6 // can be a digital pin

// define touchscreen pressure points
#define MINPRESSURE 10
#define MAXPRESSURE 1000

// Define touchscreen parameters
// Use test sketch to refine if necessary
#define TS_MINX 930
#define TS_MAXX 130
 
#define TS_MINY 200
#define TS_MAXY 970
 
#define STATUS_X 10
#define STATUS_Y 65

MCUFRIEND_kbv tft; // Define object for TFT display
TouchScreen ts = TouchScreen(XP, YP, XM, YM, 300); // Define object for touchscreen / Last parameter is X-Y resistance, measure or use 300 if unsure

//////////////////////////////////
// Motor Setup
//////////////////////////////////

//motor pins
int ENABLE_PIN = 23;
int STEP_PIN = 25;
int DIR_PIN = 27;
int stepsPerRev = 3200; // 360°/1.8° = 200 Steps x 16 Microsteppint = 3200 Microsteps/Rev

//microstepping Pins M1 =A8, M2=A9, M3=A10
//TABELLE, Abschnitt Software: https://www.mega-testberichte.de/testbericht/einen-kameraslider-motorisieren-arduino-a4988-steppermotor-touchdisplay-do-it-yourself
//pin mappings 
int M1 = A8;
int M2 = A9;
int M3 = A10;

MoToStepper stepper (stepsPerRev, STEPDIR);
MoToTimer stepperPause;   // Pause between stepper moves for timelapse
short motorDirection = 1; // clockwise

//--basic values for movement
int speed_set = 600;
int raise_speed_by = 60;
int speed_max = 1200; // -> 10.000 with Microstepping. -> 1.200 without Microstepping
long distance_set = 17000;
int raise_distance_by = 1000;
int ramp_set = 0;
short ramp_steps_by = 100;

//--"more special" variables 
bool return_to_home = false;
bool manual_start_or_stop = true; // true == start, false = stop
short distance_special_select = 1; // 1 = all normal Distances, 2 = Short Slider Length, 3 = Long Slider Length
bool stepperRunning;
long currentPos = 0;

//--needed for timelapse, buttons
long time_set = 0; 
short raise_time_by = 1;
int time_max = 900; // 15min
long ms_time = 0;

//--subdivisions for timelapse
int steps_set = 2; // Divider for Stops. So minimum drive half of the distance, stop, wait for delay, drive to end. Distance between stops is distance_set/steps_set
short steps_max = 1000; // Maximum subdivisions for timelapse system. Arbitrary number, choose to your liking
short raise_steps_by = 1;
int steps_count = 0;

//--slider length in steps
long slider_length_long = 36000; 
long slider_length_short = 18000;

//////////////////////////////////
//  Draw UI  
//////////////////////////////////

char buttonRadius = 10;
char buttonHeight = 60;
char buttonSpacing = 10;
uint16_t smallButtonWidth = 147;
uint16_t bigButtonWidth = 303;

// Define button array object
Adafruit_GFX_Button buttons[11];

  void drawButtons() {

// Create Buttons - initButton would create a Button from x and y coordinates in it's center. initButtonUL uses the top left corner
     buttons[0].initButtonUL(&tft, buttonSpacing, buttonSpacing, bigButtonWidth, buttonHeight, WHITE, DARKCYAN, WHITE, "NORMAL", 3); // NORMAL Button
        int speed_percentage = speed_set/12;
        int_to_string(speed_percentage, text_buffer); 
        sprintf(text_buffer,"%s%s",text_buffer,"%");
     buttons[1].initButtonUL(&tft, bigButtonWidth+2*buttonSpacing, buttonSpacing, smallButtonWidth, buttonHeight, WHITE, DARKGREY, WHITE, text_buffer, 3); // SPEED Button (set number)
     buttons[2].initButtonUL(&tft, buttonSpacing, buttonHeight+2*buttonSpacing, smallButtonWidth, buttonHeight, WHITE, RED, WHITE, "MANUAL", 3); // MANUAL Button
     buttons[3].initButtonUL(&tft, 2*buttonSpacing+smallButtonWidth, buttonHeight+2*buttonSpacing, smallButtonWidth, buttonHeight, WHITE, DARKGREY, WHITE, "RTH", 3); // RTH Button
          int_to_string(distance_set, text_buffer); 
     buttons[4].initButtonUL(&tft, 2*smallButtonWidth+3*buttonSpacing, 1*buttonHeight+2*buttonSpacing, smallButtonWidth, buttonHeight, WHITE, DARKGREY, WHITE, text_buffer, 3); // DIST Button (set number)
     buttons[5].initButtonUL(&tft, buttonSpacing, 2*buttonHeight+3*buttonSpacing, smallButtonWidth, buttonHeight, WHITE, DARKGREY, WHITE, "-->|", 3); // RETURN Button          
     buttons[6].initButtonUL(&tft, smallButtonWidth+2*buttonSpacing, 2*buttonHeight+3*buttonSpacing, smallButtonWidth, buttonHeight, WHITE, DARKGREY, WHITE,"<<" , 3); // DIRECTION Button 
     int_to_string(ramp_set, text_buffer);  
     buttons[7].initButtonUL(&tft, 2*smallButtonWidth+3*buttonSpacing, 2*buttonHeight+3*buttonSpacing, smallButtonWidth, buttonHeight, WHITE, DARKGREY, WHITE, text_buffer, 3);// RAMP Button (set number)
     buttons[8].initButtonUL(&tft, buttonSpacing, 3*buttonHeight+4*buttonSpacing, smallButtonWidth, buttonHeight, WHITE, ORANGE, WHITE, "TIMELAP", 3);// TIMELAPSE START Button
          int_to_string(time_set*1000, text_buffer);  
     buttons[9].initButtonUL(&tft, smallButtonWidth+2*buttonSpacing, 3*buttonHeight+4*buttonSpacing, smallButtonWidth, buttonHeight, WHITE, ORANGE, WHITE, text_buffer, 3);// DELAY Button (set number)
          int_to_string(steps_set, text_buffer);  
     buttons[10].initButtonUL(&tft, 2*smallButtonWidth+3*buttonSpacing, 3*buttonHeight+4*buttonSpacing, smallButtonWidth, buttonHeight, WHITE, ORANGE, WHITE, text_buffer, 3); // STEPS Button (set number)

// Draw Buttons
        for(uint8_t buttonCounter = 0; buttonCounter <= 10; buttonCounter++) 
        {
        buttons[buttonCounter].drawButton();
        }

// Draw Info Texts for set number Buttons

    tft.setTextSize(1);
    tft.setTextColor(WHITE); 

    tft.setCursor(bigButtonWidth+2*buttonSpacing+60,buttonSpacing+5);  tft.print("SPEED");
    tft.setCursor(bigButtonWidth+2*buttonSpacing+50,2*buttonSpacing+buttonHeight+5);  tft.print("DISTANCE");  
    tft.setCursor(bigButtonWidth+2*buttonSpacing+60,3*buttonSpacing+2*buttonHeight+5);  tft.print("RAMP");  
    tft.setCursor(bigButtonWidth+2*buttonSpacing+40,4*buttonSpacing+3*buttonHeight+5);  tft.print("SUBDIVISIONS");  
    tft.setCursor(smallButtonWidth+2*buttonSpacing+60,4*buttonSpacing+3*buttonHeight+5);  tft.print("DELAY");  

    tft.fillRect(0, tft.height()-30, tft.width(), 30, LIGHTGREY); // Infobar
}

/*************************
**  Required functions  **
*************************/
void setup() {  

tft.reset();

  // basic motor setup
/*
  // Microstepping - disabled due to the use of Planetary Gear. Enable it, if you are using a "normal" stepper motor.
  pinMode(M1, OUTPUT);
  pinMode(M2, OUTPUT);
  pinMode(M3, OUTPUT);

  //see table for step values: https://lastminuteengineers.com/a4988-stepper-motor-driver-arduino-tutorial/
  digitalWrite(M1, HIGH);
  digitalWrite(M2, HIGH);
  digitalWrite(M3, HIGH);
  */
  stepper.attach( STEP_PIN, DIR_PIN );
  stepper.attachEnable (ENABLE_PIN,1,LOW); // Set Enable Pin and Turn of Motor per Default

  // Setup the Display
  tft.begin(tft.readID());
  tft.setRotation(1);
  tft.fillScreen(BLACK);

  //call function to draw our gui  
  drawButtons();
  
  Serial.begin(115200); 
  Serial.println("Starting Slider Control V2.1 by Gregor Urabl \r\n");  
  Serial.print("TFT size is "); Serial.print(tft.width()); Serial.print("x"); Serial.println(tft.height());
  
    stepperRunning = true;
    stepper.setZero(0); //set current Position as 0 
    pingTimer = millis(); // Start Timer
    photo_counter = 0; // Reset photo counter

   // Detection of attached module - Sonar or Camera
   if(sonar.ping(MAX_DISTANCE)!=0){ // Make one Ping on max Distance to test if ultrasonic module is attached
      tft.fillRect(tft.width()-10, 0, 10, 10, GREEN); // Green Bar shows that Ultrasonic Sensor has been connected
      Serial.println("Sonar Module attached.");
      sonar_attached = true;
      camera_attached = false;
    } else {
      // If sonar test fails, assume camera module is attached
      pinMode(TRIGGER_PIN, OUTPUT); // Set trigger pin as output for camera
      digitalWrite(TRIGGER_PIN, HIGH); // Set default state to HIGH (open circuit)
      tft.fillRect(tft.width()-10, 0, 10, 10, BLUE); // Blue Bar shows that Camera Module has been connected
      Serial.println("Camera Module attached - Sonar test failed.");
      camera_attached = true;
      sonar_attached = false;
      }
}

void loop() {

// start optional sonar module
if (millis() >= pingTimer && sonar_attached == true) {   // pingSpeed milliseconds since last ping, do another ping.
    pingTimer += pingSpeed;      // Set the next ping time.
    sonar.ping_timer(echoCheck); // Send out the ping, calls "echoCheck" function every 24uS where you can check the ping status.
  }

    //touchscreen
  uint16_t i;
  digitalWrite(13, HIGH);
  TSPoint p = ts.getPoint();
  digitalWrite(13, LOW);

  pinMode(XM, OUTPUT);
  pinMode(YP, OUTPUT);
  if (p.z > MINPRESSURE && p.z < MAXPRESSURE)
  {

    p.x = map(p.x, TS_MINX, TS_MAXX, tft.width(),0);
    p.y = map(p.y, TS_MINY, TS_MAXY, tft.height(),0);

      //debug
      //check the area where we drew the buton for touch
      /*
      Serial.print("Touch X is:");
      Serial.print(p.x);
      Serial.print("\r\n");

      Serial.print("Touch Y is:");
      Serial.print(p.y);
      Serial.print("\r\n");*/

      //--------------------NORMAL button 
      if ((p.y >= 10) && (p.x >= 40) && (p.y <= 220) && (p.x <= 100) ) { 
      doNormalRun(speed_set,ramp_set,distance_set); //go to function, because this can also be triggered by Serial Communication
      }

      //--------------------SPEED button with UPDATE of number
     if ((p.y >= 240) && (p.x >= 40) && (p.y <= 330) && (p.x <= 110) ) {   

        //one touch raises speed by X up to "speed_max"
        if(speed_set < speed_max) {
          speed_set = speed_set + raise_speed_by;  
        }
        else {
          speed_set = 60;
        }       
        int speed_percentage = speed_set/12;
        int_to_string(speed_percentage, text_buffer); 
        sprintf(text_buffer,"%s%s",text_buffer,"%");
        buttons[1].initButtonUL(&tft, bigButtonWidth+2*buttonSpacing, buttonSpacing, smallButtonWidth, buttonHeight, WHITE, DARKGREY, WHITE, text_buffer, 3); // SPEED Button (set number)
        redrawButtons(1,bigButtonWidth+2*buttonSpacing+60,buttonSpacing+5,"SPEED");

        String speedMsg = "Speed set to ";
        speedMsg.concat(text_buffer);
        updateStr(speedMsg);
     }

      //--------------------MANUAL button
      if ((p.y >= 10) && (p.x >= 140) && (p.y <= 100) && (p.x <= 210) ) { 
      
      //Set Basic Speed and Acceleration/Ramp of each Steppers at startup
      stepper.setMaxSpeed(speed_set);
      stepper.setRampLen(ramp_set); 

      if(manual_start_or_stop == true){ //start run on first click   
      currentPos = stepper.currentPosition();
      updateStr("Manual Run");
      stepper.rotate(motorDirection);
      manual_start_or_stop = !manual_start_or_stop;
      }
      else{ // stop run on second click
         long traveled_distance = stepper.currentPosition()-currentPos;
         String traveledMsg = "Manual Run stopped after ";
            if(traveled_distance<0){traveled_distance*=-1;}
        traveledMsg.concat(traveled_distance);
        traveledMsg.concat(" Steps.");
        updateStr(traveledMsg);
        manual_start_or_stop = !manual_start_or_stop;
          if(return_to_home == true){          
                updateStr("Returning Home"); 
                stepper.moveTo(currentPos);            
          } else{stepper.stop();} //motor off 
          }
      }

         //--------------------RTH button
      if ((p.y >= 120) && (p.x >= 140) && (p.y <= 220) && (p.x <= 210) ) { 
          rth();
      }   

      //--------------------DISTANCE button with UPDATE of number
     if ((p.y >= 235) && (p.x >= 140) && (p.y <= 320) && (p.x <= 220) ) {   
        
        if(distance_special_select == 3) // Check if Slider was set to SHORT Distance on the last press. If so, reset the button back to Zero
          {
          distance_set = 0;
          int_to_string(distance_set, text_buffer); 
          distance_special_select = 1;
        }   
         else if(distance_set < slider_length_long-raise_distance_by) { // If the Button is not set to SHORT or LONG, one touch raises Distance by X up to Slider Length. As LONG is equivalent to  "slider_length_long" we have to break one "raise_distance_by" before that happens.
          distance_set = distance_set + raise_distance_by;  
          int_to_string(distance_set, text_buffer); 
          distance_special_select = 1;
          }
          else if(distance_set == slider_length_long-raise_distance_by && distance_special_select == 1) // If Distance is one step away from LONG, raise it one last time an set the special select var so we know to stop counting the normal way now
          {
            distance_set = slider_length_long;  
          strcpy(text_buffer,"LONG");
          distance_special_select = 2;
          }
          else if(distance_special_select == 2) // We are on LONG, show SHORT next.
          {
          strcpy(text_buffer,"SHORT");
          distance_set = slider_length_short;
          distance_special_select = 3;
          }
         
      buttons[4].initButtonUL(&tft, bigButtonWidth+2*buttonSpacing, 1*buttonHeight+2*buttonSpacing, smallButtonWidth, buttonHeight, WHITE, DARKGREY, WHITE, text_buffer, 3); // DIST Button (set number)
      redrawButtons(4,bigButtonWidth+2*buttonSpacing+50,2*buttonSpacing+buttonHeight+5,"DISTANCE"); 

        String distMsg = "Travel Distance set to ";
        distMsg.concat(text_buffer);
        updateStr(distMsg);
     }

      //--------------------RETURN/ NO RETURN button
      if ((p.y >= 10) && (p.x >= 250) && (p.y <= 100) && (p.x <= 310) ) {   

      return_to_home = !return_to_home;

      if(return_to_home == true){
         buttons[5].initButtonUL(&tft, buttonSpacing, 2*buttonHeight+3*buttonSpacing, smallButtonWidth, buttonHeight, WHITE, DARKGREY, WHITE, "<-->", 3);
         buttons[5].drawButton();
         updateStr("Return Mode set to RETURN"); 
        } else{
         buttons[5].initButtonUL(&tft, buttonSpacing, 2*buttonHeight+3*buttonSpacing, smallButtonWidth, buttonHeight, WHITE, DARKGREY, WHITE, "-->|", 3);
         buttons[5].drawButton();
         updateStr("Return Mode set to SINGLE RUN");
        }

        }

      //--------------------DIRECTION button
      if ((p.y >= 125) && (p.x >= 245) && (p.y <=220) && (p.x <= 315) ) {   
        
        motorDirection *= -1; // invert it

        if(motorDirection == -1){
         buttons[6].initButtonUL(&tft, smallButtonWidth+2*buttonSpacing, 2*buttonHeight+3*buttonSpacing, smallButtonWidth, buttonHeight, WHITE, DARKGREY, WHITE,">>" , 3); // DIRECTION Button 
         buttons[6].drawButton();
         updateStr("Direction set set to "); tft.write(0x10);tft.write(0x10);tft.write(" CW");
        } else{
         buttons[6].initButtonUL(&tft, smallButtonWidth+2*buttonSpacing, 2*buttonHeight+3*buttonSpacing, smallButtonWidth, buttonHeight, WHITE, DARKGREY, WHITE,"<<" , 3); // DIRECTION Button 
         buttons[6].drawButton();
         updateStr("Direction set set to "); tft.write(0x11);tft.write(0x11);tft.write(" CCW");
        }
      
      }

      //--------------------RAMP button with UPDATE of number
      if ((p.y >= 235) && (p.x >= 250) && (p.y <=325) && (p.x <= 320) ) {
        //one touch raises Ramp by X up to (slider_length_long/2)
        if(ramp_set < distance_set/2) { 
          ramp_set = ramp_set + ramp_steps_by;  
        }
        else {
          ramp_set = 0;
        }        

        int_to_string(ramp_set, text_buffer); 
        buttons[7].initButtonUL(&tft, 2*smallButtonWidth+3*buttonSpacing, 2*buttonHeight+3*buttonSpacing, smallButtonWidth, buttonHeight, WHITE, DARKGREY, WHITE, text_buffer, 3);// RAMP Button (set number)
        redrawButtons(7,bigButtonWidth+2*buttonSpacing+60,3*buttonSpacing+2*buttonHeight+5,"RAMP");

        String rampMsg = "Ramp set to ";
        rampMsg.concat(text_buffer);
        updateStr(rampMsg);
      }      

      //------------------------TIMELAPSE START button 
      if ((p.y >= 10) && (p.x >= 350) && (p.y <= 100) && (p.x <= 420) ) {          
      doTimelapse(speed_set, time_set, steps_set, distance_set);
      }     

      //------------------------DELAY button with UPDATE of number
      if ((p.y >= 125) && (p.x >= 360) && (p.y <= 220) && (p.x <= 420) ) {    // if ((p.y >= 125) && (p.x >= 360) && (p.y <= 220) && (p.x <= 420) ) { 

        //one touch raises time by X up to time_max
        if(time_set < time_max) {
          time_set = time_set + raise_time_by;  
          
        }
        else {
          time_set = 0;
        }             

        int_to_string(time_set, text_buffer); 
        buttons[9].initButtonUL(&tft, smallButtonWidth+2*buttonSpacing, 3*buttonHeight+4*buttonSpacing, smallButtonWidth, buttonHeight, WHITE, ORANGE, WHITE, text_buffer, 3);// DELAY Button (set number)    
        redrawButtons(9,smallButtonWidth+2*buttonSpacing+60,4*buttonSpacing+3*buttonHeight+5,"DELAY"); 

        String timeMsg = "Delay for Timelapse set to ";
        timeMsg.concat(text_buffer);
        updateStr(timeMsg);
      }      

       //------------------------STEPS button with UPDATE of number 
      if ((p.y >= 230) && (p.x >= 360) && (p.y <= 310) && (p.x <= 410) ) {    
        //one touch raises steps by 1 up to steps_max
        if(steps_set < steps_max) {
          steps_set = steps_set + raise_steps_by;  
        }
        else {
          steps_set = 2;
        }       

        int_to_string(steps_set, text_buffer); 
        buttons[10].initButtonUL(&tft, 2*smallButtonWidth+3*buttonSpacing, 3*buttonHeight+4*buttonSpacing, smallButtonWidth, buttonHeight, WHITE, ORANGE, WHITE, text_buffer, 3); // STEPS Button (set number)
        redrawButtons(10,bigButtonWidth+2*buttonSpacing+40,4*buttonSpacing+3*buttonHeight+5,"SUBDIVISIONS"); 

        String stepsMsg = "Subdivisions set to ";
        stepsMsg.concat(text_buffer);
        updateStr(stepsMsg);
      }    
}
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

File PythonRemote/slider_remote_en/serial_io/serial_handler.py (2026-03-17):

# =============================================================================
# serial_io/serial_handler.py – Serial communication
# Wraps pyserial. Sends commands and reads responses from the controller.
# Reading runs in a background thread so the UI is never blocked.
# =============================================================================

from typing import List
import threading
import time
import serial
import serial.tools.list_ports
from config import SERIAL_BAUD, SERIAL_TIMEOUT


def list_ports() -> List[str]:
    """Returns available serial ports, USB/ACM ports sorted first."""
    all_ports = [port.device for port in serial.tools.list_ports.comports()]
    usb_ports = [p for p in all_ports if "USB" in p or "ACM" in p or "usbserial" in p or "cu." in p]
    other_ports = [p for p in all_ports if p not in usb_ports]
    return usb_ports + other_ports


class SerialHandler:
    def __init__(self, on_receive=None):
        # on_receive: primary callback(str) for incoming controller messages
        self._port = None
        self._on_receive = on_receive
        self._extra_listeners = []
        self._read_thread = None
        self._running = False

    def add_listener(self, callback):
        """Registers an additional receive callback (e.g. calibration window)."""
        if callback not in self._extra_listeners:
            self._extra_listeners.append(callback)

    def remove_listener(self, callback):
        """Removes a previously registered extra callback."""
        if callback in self._extra_listeners:
            self._extra_listeners.remove(callback)

    def connect(self, port: str) -> bool:
        """Opens the connection to the selected COM port. Returns True on success."""
        try:
            self._port = serial.Serial(port, SERIAL_BAUD, timeout=SERIAL_TIMEOUT)
            # Arduino resets on DTR when the port opens – wait for it to finish booting
            time.sleep(2)
            self._running = True
            self._read_thread = threading.Thread(target=self._read_loop, daemon=True)
            self._read_thread.start()
            return True
        except serial.SerialException as e:
            self._port = None
            raise ConnectionError(f"Connection to {port} failed: {e}")

    def disconnect(self):
        """Closes the connection cleanly."""
        self._running = False
        if self._port and self._port.is_open:
            self._port.close()
        self._port = None

    def is_connected(self) -> bool:
        return self._port is not None and self._port.is_open

    def send(self, command: str):
        """Sends a command as a line (with \\n terminator) to the controller."""
        if not self.is_connected():
            raise ConnectionError("Not connected.")
        # Arduino parser expects \\n as the terminating character
        self._port.write((command + "\n").encode("utf-8"))
        self._port.flush()

    def build_normal_command(self, speed: int, distance: int, ramp: int) -> str:
        """Builds the serial command string for Normal mode."""
        return f"normal,{speed},{distance},{ramp},0,2"

    def build_timelapse_command(self, speed: int, distance: int, ramp: int,
                                time_s: int, subdivisions: int) -> str:
        """Builds the serial command string for Timelapse mode."""
        return f"timelapse,{speed},{distance},{ramp},{time_s},{subdivisions}"

    def build_rth_command(self) -> str:
        return "rth"

    def build_start_command(self) -> str:
        return "start"

    def build_stop_command(self) -> str:
        return "stop"

    def build_direction_command(self, direction: int) -> str:
        """Sets motorDirection on the Arduino. direction: 1=Forward, -1=Reverse."""
        return f"direction,{direction},0,0,0,0"

    def _read_loop(self):
        """Background thread: continuously reads responses from the controller."""
        while self._running and self._port and self._port.is_open:
            try:
                line = self._port.readline().decode("utf-8", errors="replace").strip()
                if line:
                    if self._on_receive:
                        self._on_receive(line)
                    for cb in list(self._extra_listeners):
                        cb(line)
            except serial.SerialException:
                self._running = False
                if self._on_receive:
                    self._on_receive("[Connection lost]")

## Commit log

2026-03-02 Documentation Update, Added Readme
    [Slidercontrol_V2_1_Corrected.kicad_sch]
2026-03-03 Manual Update & Cleanup
    [Slidercontrol_V2_1_Corrected.kicad_sch]
2026-03-05 Added STLs
    [Shark Antriebs Pulley.stl, Shark Antriebsrad fuer Getriebe 8mm.stl, Shark Nema 17 Deckel.stl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]
2026-03-05 Added Schematic
    [Slidercontrol_V2_1_Corrected.kicad_sch]
